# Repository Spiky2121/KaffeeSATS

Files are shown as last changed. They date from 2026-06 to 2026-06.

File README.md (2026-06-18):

# ☕⚡ KaffeeSATS

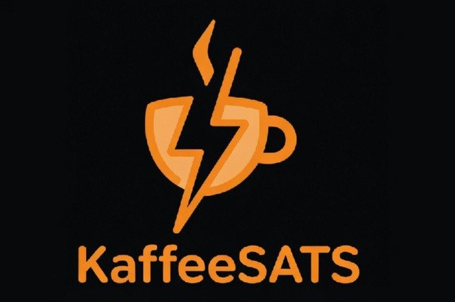
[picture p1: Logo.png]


## Pay With Lightning. Drink Coffee.

### Open-Source Bitcoin Coffee Machines

---

# 🌐 Project Website

## https://spiky2121.github.io/KaffeeSATS/

---

# 💻 GitHub Repository

## https://github.com/Spiky2121/KaffeeSATS

---

### ⚡ Features

* Lightning Payments
* Bolt Card NFC Support
* LNbits Offline Bitcoin Switch
* ZapBox Online Edition
* Bosch Tassimo Integration
* 3D Printed Parts
* Open Source Hardware
* Open Source Documentation

---

### ☕ Two Bitcoin Coffee Machines

#### 🔐 Offline Bitcoin Switch Edition

* Sunton ESP32-3248S035
* LNbits Offline Bitcoin Switch
* PIN-based Coffee Unlock
* Fully Offline Payment Verification

#### 💳 ZapBox Online Edition

* ZapBox Compact
* Lightning QR Payments
* Bolt Card NFC Payments
* Instant Coffee Unlock

---

### 📚 Documentation

* Wiring Guides
* Block Diagrams
* Build Instructions
* Hardware Modifications
* Safety Notes

---

### 🧩 Downloads

* A3 Conference Posters
* Wiring Diagrams
* 3D Print Files
* STEP Files
* Sticker Artwork

---

### 🚀 Project Goal

KaffeeSATS demonstrates how Bitcoin Lightning payments can interact with real-world hardware.

Scan. Pay. Press. Enjoy Coffee.

Built by a Bitcoiner, for Bitcoiners.

# Version 1: ☕ KaffeeSATS Offline Edition Bitcoin Switch

### Offline Lightning PIN System

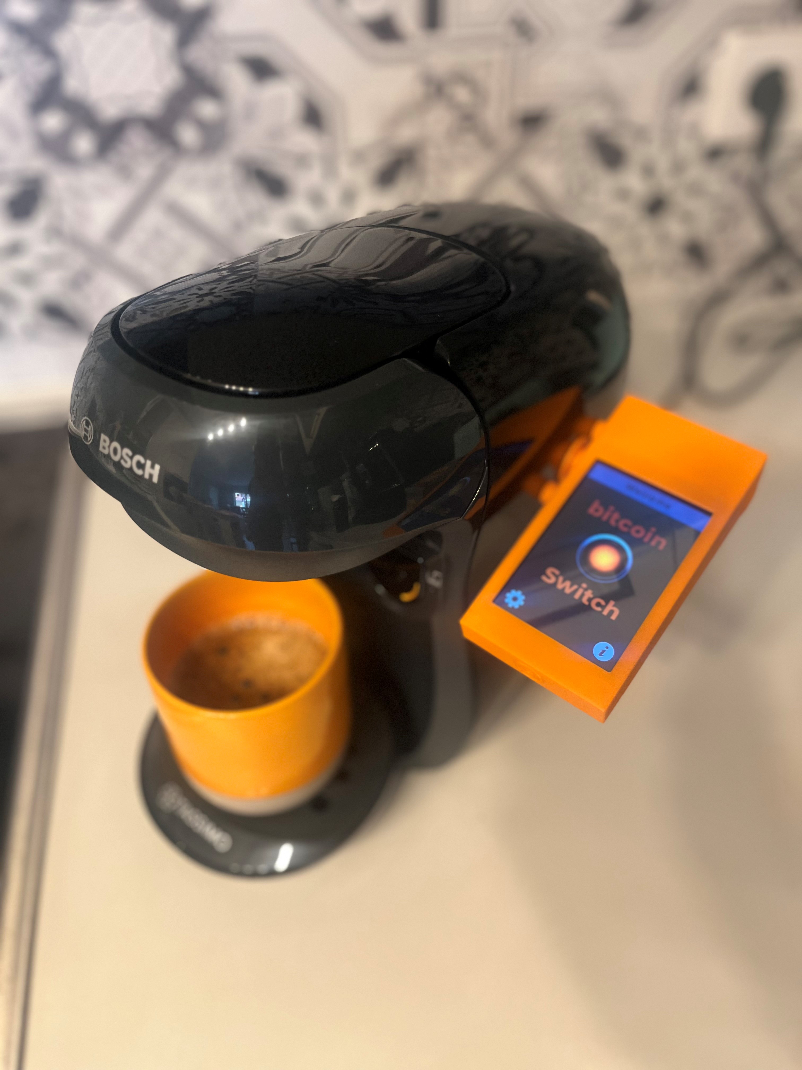
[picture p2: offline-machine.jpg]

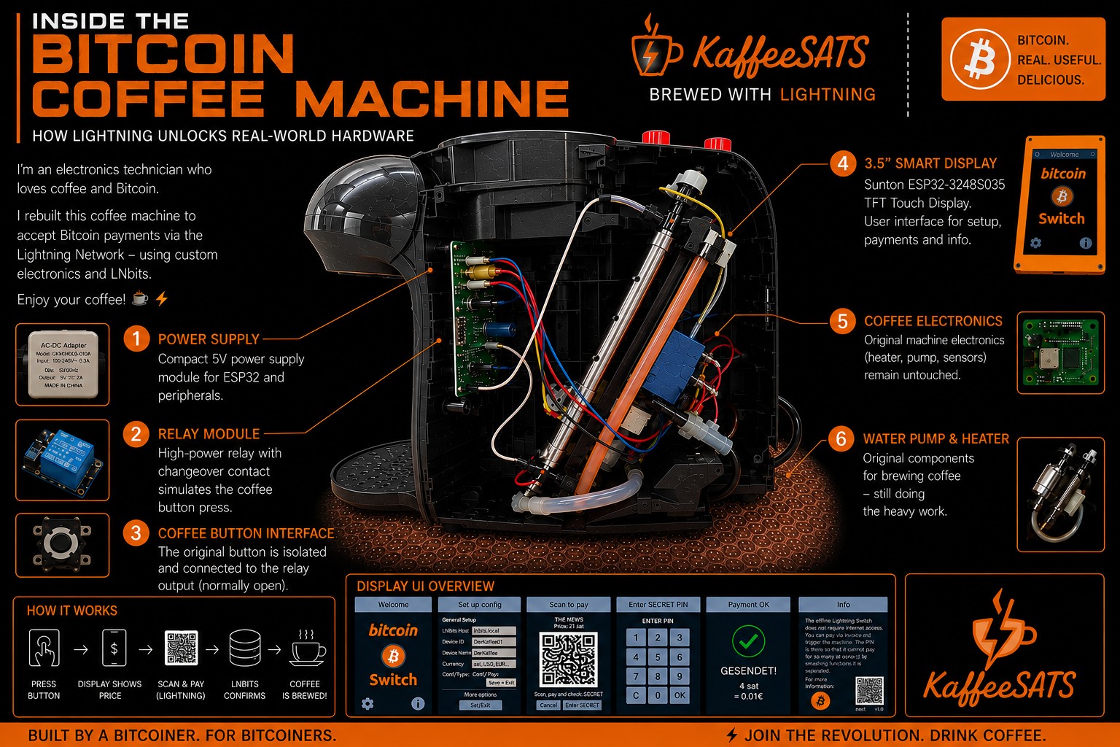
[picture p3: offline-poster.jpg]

Hardware:

* Sunton ESP32-3248S035 Smart Display
* LNbits Offline Bitcoin Switch
* Internal Relay Interface
* Bosch Tassimo Coffee Machine

How it works:

1. Scan Lightning invoice
2. Pay with any Lightning wallet
3. Receive a secret PIN
4. Enter PIN on the display
5. Relay activates
6. Press coffee button
7. Coffee brewing starts

Advantages:

* Works without permanent internet connection
* No external controller required
* Great demonstration of the LNbits Offline Bitcoin Switch

# ☕ KaffeeSATS Offline Edition – Wiring Guide

## Components

* 230V → 5V AC/DC Power Supply
* Sunton ESP32-3248S035 Display
* 5V Relay Module
* Bosch Tassimo Main Control Board
* Original Tassimo Start Button

---

## Power Supply

### AC Side

230V AC Supply:

* L (Live) → Power Supply Input L
* N (Neutral) → Power Supply Input N

### DC Side

Power Supply Output:

* +5V → Sunton ESP32 USB Power Input
* GND → Sunton ESP32 USB Power Input

---

## ESP32 → Relay Connection

The 3-pin connector on the side of the Sunton display is used:

| ESP32 | Relay |
| --- | ----- |
| Red (+5V) | VCC |
| Black (GND) | GND |
| Yellow (Signal) | IN |

The ESP32 controls the relay through the signal wire.

---

## Relay Contact

Only the isolated dry-contact output of the relay is used.

### Contact 1

Relay COM →

Button Pin 2

(Pin 2 of the original button is bent upward and electrically isolated.)

### Contact 2

Relay NO →

Neutral (N) connection on the Tassimo control board

---

## Button Modification

Original Button Layout:

| Pin | Function |
| --- | --- |
| 1 | Original Contact |
| 2 | Connected to Relay |
| 3 | Cut Off / Not Used |
| 4 | Original Contact |

Required Modifications:

* Bend Pin 2 upward
* Cut off Pin 3
* Connect relay contact to Pin 2

---

## Operating Principle

1. User scans Lightning invoice
2. Payment is confirmed
3. ESP32 activates relay
4. Relay connects:

   * Button Pin 2
   * Neutral point on the control board
5. Coffee machine becomes enabled
6. User presses the yellow Tassimo button
7. Coffee brewing starts

---

## Safety Notice

* 230V AC wiring should only be performed by qualified personnel.
* The relay contact is galvanically isolated from the ESP32.
* All mains voltage connections must be properly insulated.
* Ensure protection against accidental contact with live parts.

---
## Project Purpose

  KaffeeSATS Offline Edition
          LNbits Offline Bitcoin Switch

               230V AC
          ┌─────────────┐
          │   L     N   │
          └──┬─────┬────┘
             │     │
             ▼     ▼

      ┌─────────────────┐
      │ 230V → 5V PSU   │
      │ AC/DC Module    │
      └─────────────────┘
             │
        +5V  │  GND
             ▼

          Sunton ESP32-3248S035
        ┌───────────────────────┐
        │                       │
        │ Red (+5V)  ───────► VCC
        │                       │
        │ Black (GND) ──────► GND
        │                       │
        │ Yellow (GPIO21) ──► IN
        │                       │
        └───────────────────────┘
                        ▼
                        ▼
                    ┌────────────────┐
                    │ 5V Relay Module│
                    │                │
                    │ VCC ← +5V      │
                    │ GND ← GND      │
                    │ IN  ← GPIO21   │
                    └─────┬──────┬───┘
                          │      │
                         COM    NO
                          │      │
                          │      │
                          ▼      ▼

                   Pin 2      Neutral (N)
               (lifted pin)   Tassimo PCB

                          │
                          ▼

                 Original Tassimo
                    Start Button

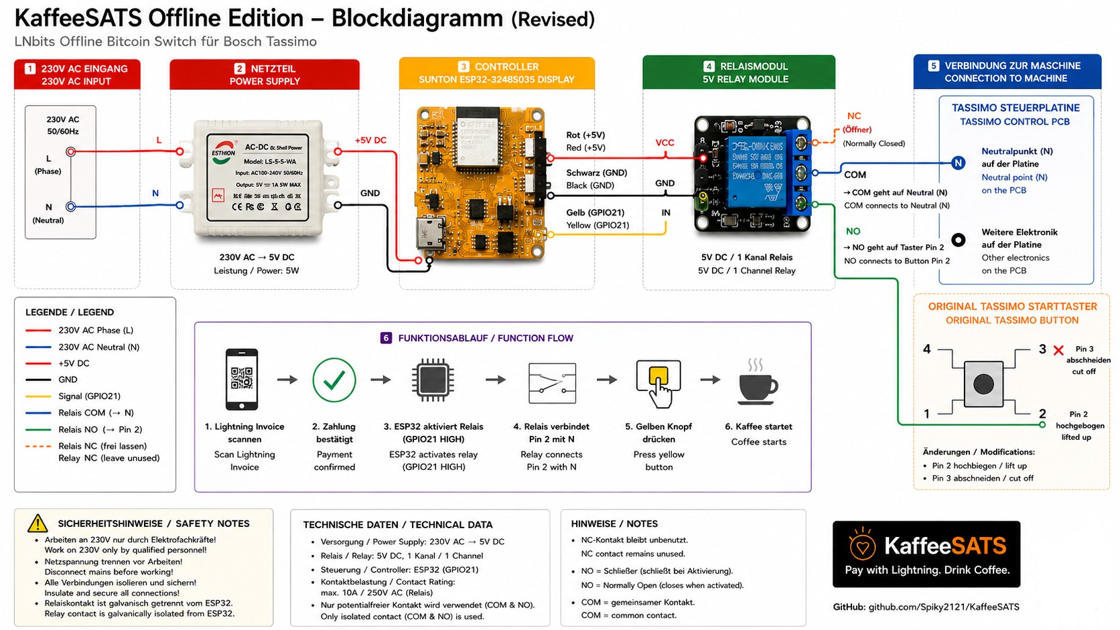
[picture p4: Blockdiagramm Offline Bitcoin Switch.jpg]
    

  # ⚡ Bitcoin Offline Switch Documentation

## https://ereignishorizont.xyz/offlinelnswitch/

# ⚡ Bitcoin Offline Switch Web Installer

## https://ereignishorizont.xyz/installer/offlineLNSwitch/index.html
---
---
---

# Version 2: ☕ KaffeeSATS Online ZapBox Edition

### Lightning & Bolt Card Enabled

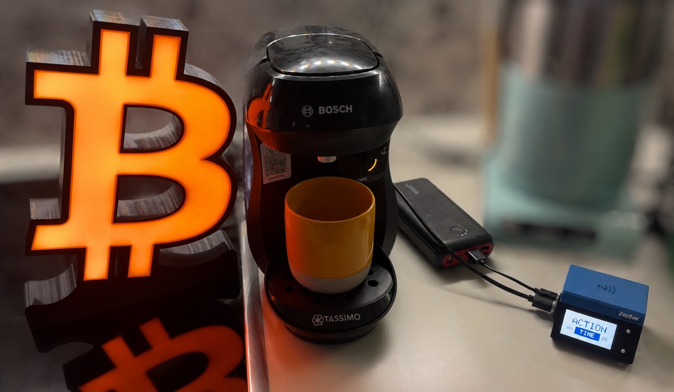
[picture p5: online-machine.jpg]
Online Version

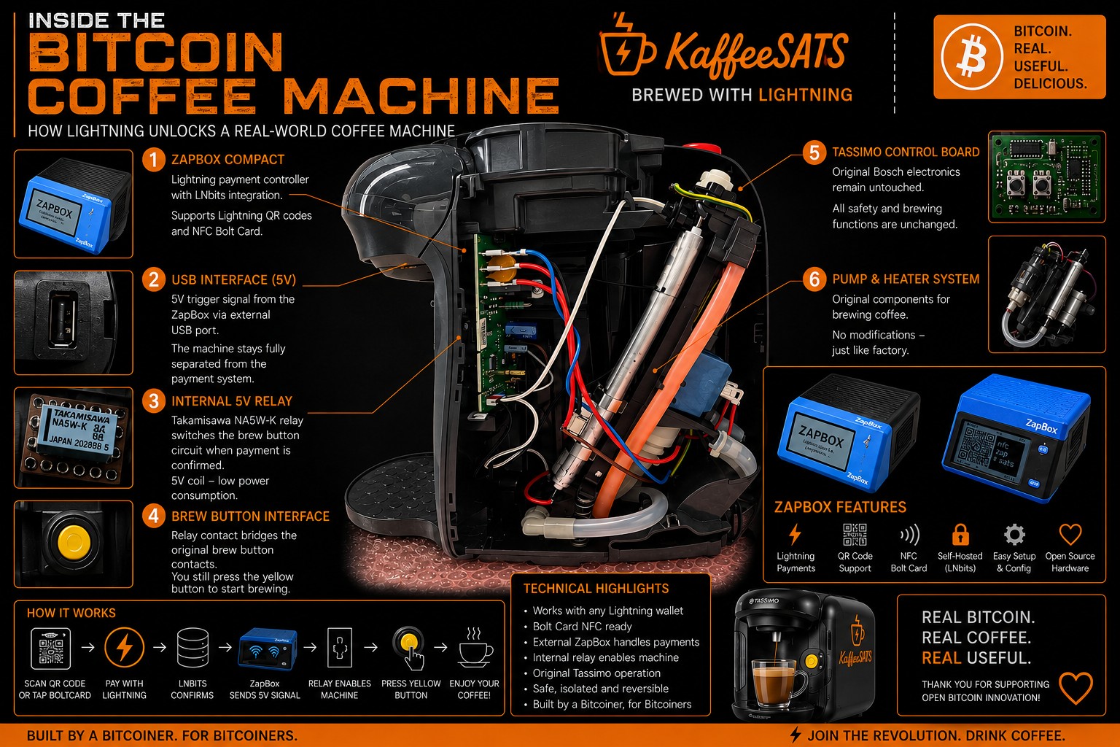
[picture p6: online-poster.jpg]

Hardware:

* ZapBox Compact
* LNbits
* Internal 5V Relay
* Bosch Tassimo Coffee Machine

How it works:

1. Scan QR Code
   or
   Tap NFC Bolt Card
2. Lightning payment is processed
3. ZapBox outputs a 5V trigger signal
4. Internal relay enables the machine
5. User presses the brew button
6. Coffee brewing starts

Advantages:

* Instant user experience
* NFC Bolt Card support
* Simple payment flow
* Perfect for conferences and public demonstrations

---

# ☕ KaffeeSATS Online Zapbox Edition - Wiring Guide

### ZapBox Lightning Payment Terminal for Bosch Tassimo

**Pay with Lightning. Drink Coffee.**

---

## Project Purpose

The KaffeeSATS Online Edition demonstrates how a Bitcoin Lightning payment can directly trigger a Bosch Tassimo coffee machine.

The ZapBox handles:

* Lightning payments
* QR code generation
* Bolt Card NFC payments
* Payment verification

After a successful payment, the ZapBox outputs **5V** via USB and activates an internal relay. The relay enables the original Tassimo start button.

---

## Hardware Components

* ZapBox Payment Terminal
* USB Power Output (5V)
* Takamisawa NA5W-K Relay
* Bosch Tassimo Control PCB
* Original Tassimo Start Button

---

## System Overview

```text
                ┌──────────────────┐
                │      ZapBox      │
                │ Lightning Wallet │
                └─────────┬────────┘
                          │
                          │ USB 5V Output
                          ▼

                ┌──────────────────┐
                │ Internal Relay   │
                │ Takamisawa NA5W-K│
                └──────┬─────┬─────┘
                       │     │
                      COM    NO
                       │     │
                       │     ▼
                       │  Neutral (N)
                       │  Tassimo PCB
                       │
                       ▼

                  Pin 2 Button
                 (lifted from PCB)

                       │
                       ▼

              Original Tassimo
                 Start Button
```

---

## USB Power Output

The ZapBox provides 5V through the internal USB connector.

| Wire  | Function |
| ----- | --- |
| Red | +5V |
| Black | GND |

Connections:

```text
ZapBox USB
----------------
Red   -> Relay Coil +
Black -> Relay Coil -
```

---

## Relay Contact Wiring

Only the isolated relay contact is used.

| Relay Contact | Connection |
| --- | --- |
| COM | Button Pin 2 |
| NO | Neutral (N) on Tassimo PCB |
| NC | Not Connected |

---

## Button Modification

Original tactile switch:

```text
4 ----- 3
|       |
|   ●   |
|       |
1 ----- 2
```

Required modification:

* Lift Pin 2 from PCB
* Connect relay COM to Pin 2
* Cut Pin 3
* Leave Pins 1 and 4 unchanged

---

## Function Flow

1. User scans Lightning invoice
2. Payment is confirmed
3. ZapBox outputs 5V
4. Internal relay activates
5. Relay connects:

   * COM → Pin 2
   * NO → Neutral (N)
6. User presses the Tassimo button
7. Coffee starts

---
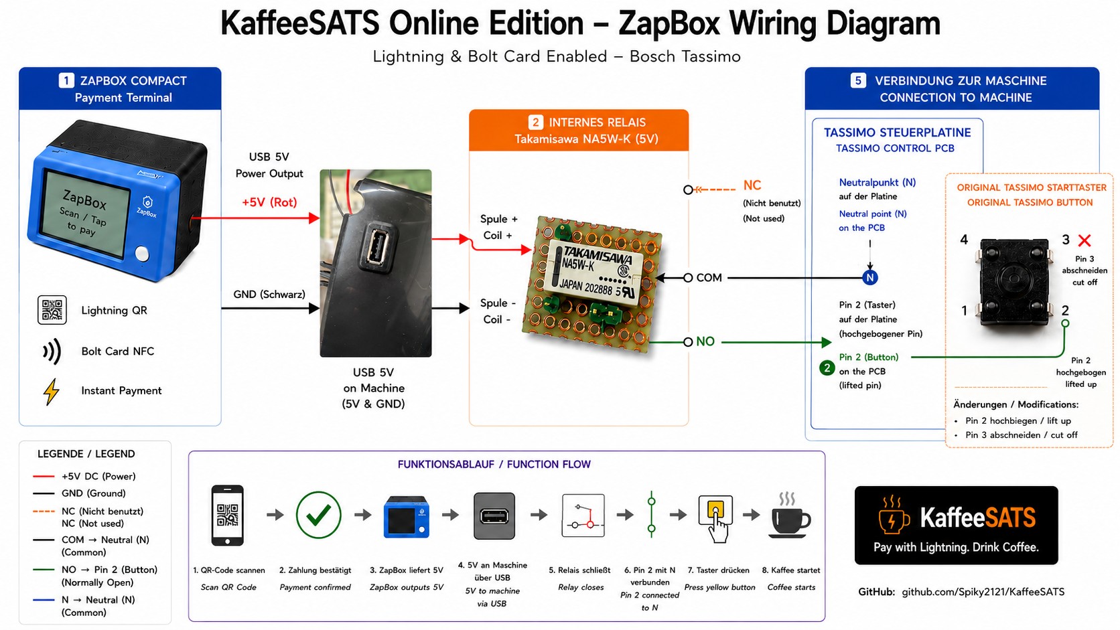
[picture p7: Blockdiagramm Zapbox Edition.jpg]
   
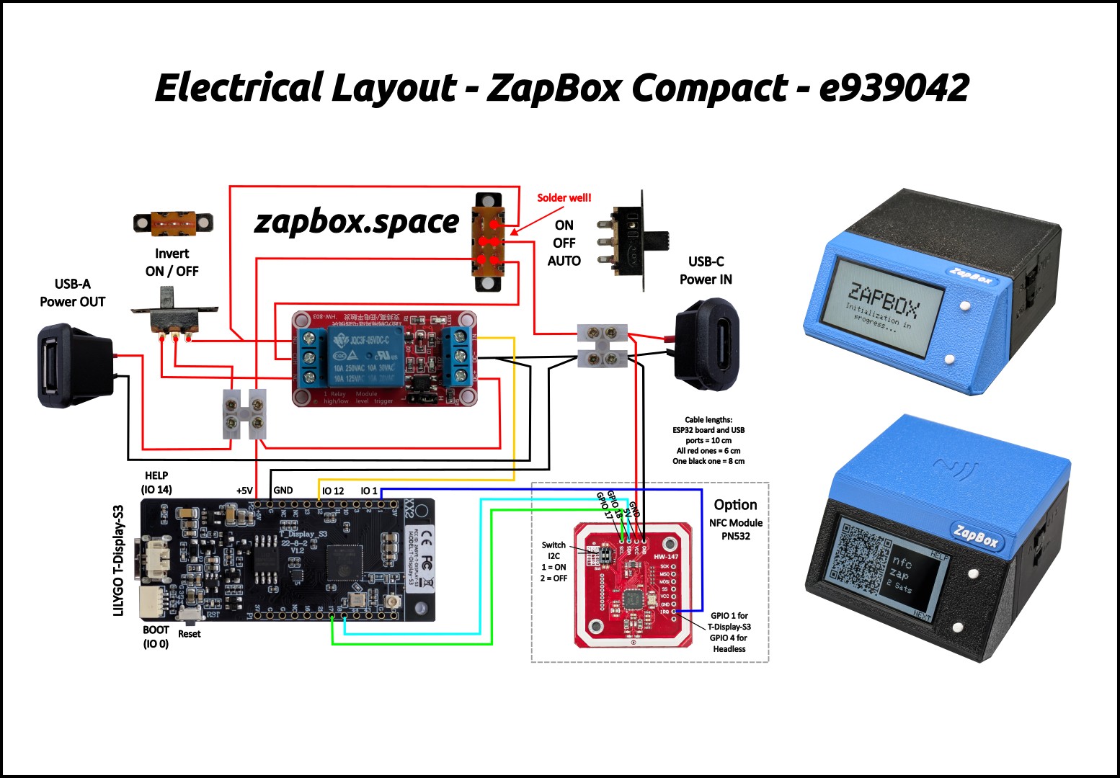
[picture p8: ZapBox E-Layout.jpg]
 

# ⚡ Zapbox Documentation
 
##  https://github.com/AxelHamburch/ZapBox
##  https://zapbox.space/

# ⚡ ZapBox Web Installer

## 👉 [Flash ZapBox Firmware](https://installer.zapbox.space/#flash)
 
## Safety Notice

⚠️ This modification involves mains-powered equipment.

* Disconnect power before working on the machine.
* Insulate all wiring properly.
* Verify relay isolation before operation.
* Only qualified persons should work on electrical equipment.

---

### KaffeeSATS

**Pay with Lightning. Drink Coffee.**

# Comparison

| Feature | Offline Switch | ZapBox |
| --- | --- | --- |
| Lightning QR | ✅ | ✅ |
| NFC Bolt Card | ❌ | ✅ |
| Secret PIN | ✅ | ❌ |
| Sunton Display | ✅ | Optional |
| ZapBox | ❌ | ✅ |
| Offline Operation | ✅ | ❌ |
| Conference Friendly | ✅ | ✅ |

---

# Why KaffeeSATS?

Bitcoin is often difficult to explain.

Coffee is not.

KaffeeSATS demonstrates Bitcoin and the Lightning Network through a real-world interaction that everyone understands.

Pay.
Press.
Enjoy.

---

## Sticker 
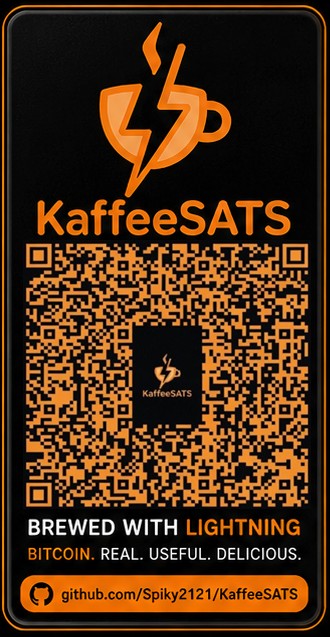
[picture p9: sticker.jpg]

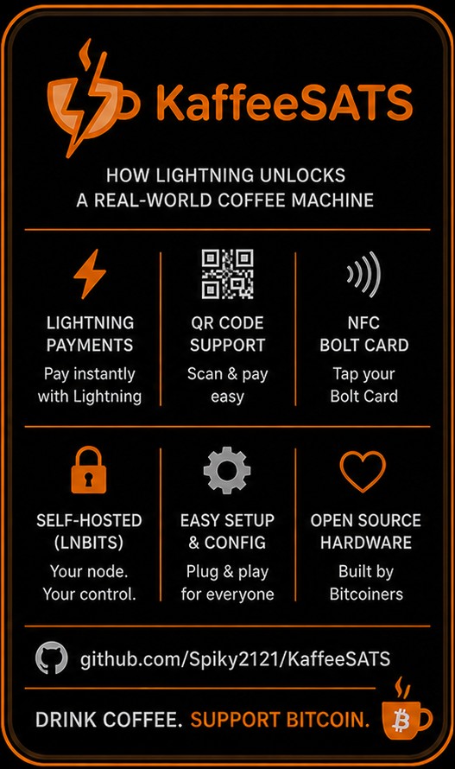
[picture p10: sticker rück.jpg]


## Business Card 
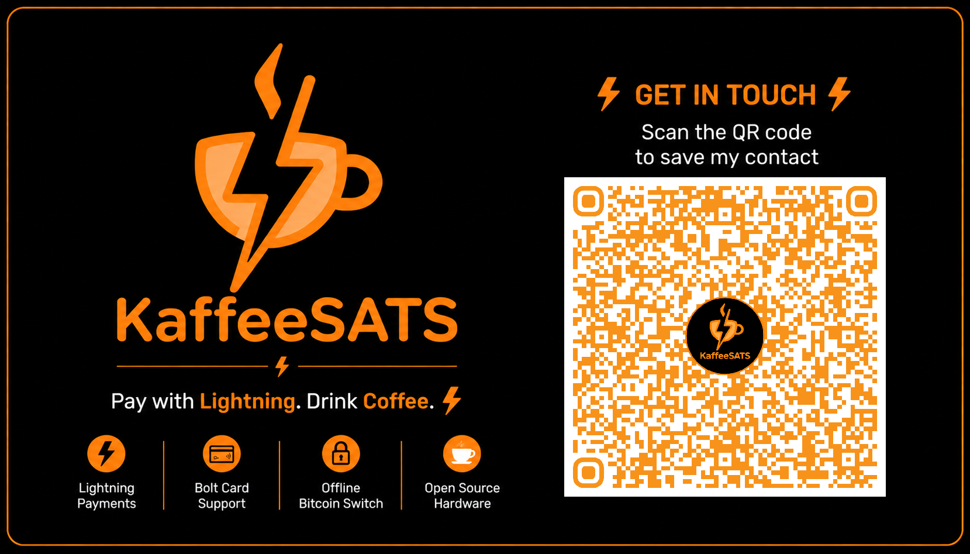
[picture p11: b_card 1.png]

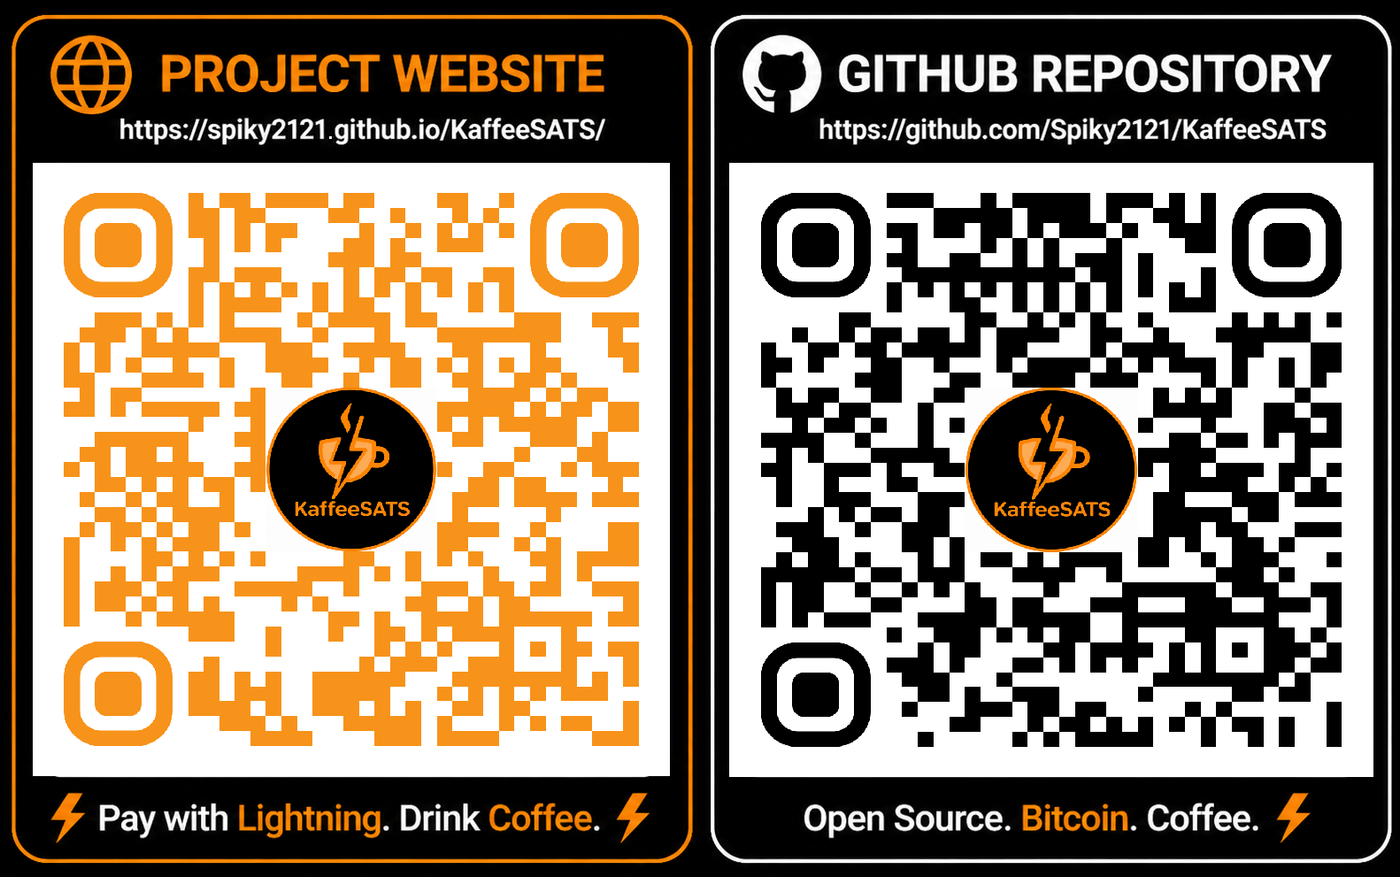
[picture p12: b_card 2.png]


# Open Source

This project is released under the MIT License.

Feel free to fork, improve and build your own Bitcoin-powered coffee machine.

## Acknowledgements

Special thanks to Axel (www.ereignishorizont.xyz) & (www.zapbox.space) for the development of ZapBox and the Offline Bitcoin Switch.
---
---
Thanks to the LNbits team and timecatcher.lnbits for providing the open-source payment infrastructure (https://lnbits.com/) & (https://timecatcher.business-bitcoin.de/)
---
---
# KaffeeSATS

### Pay With Lightning. Drink Coffee.

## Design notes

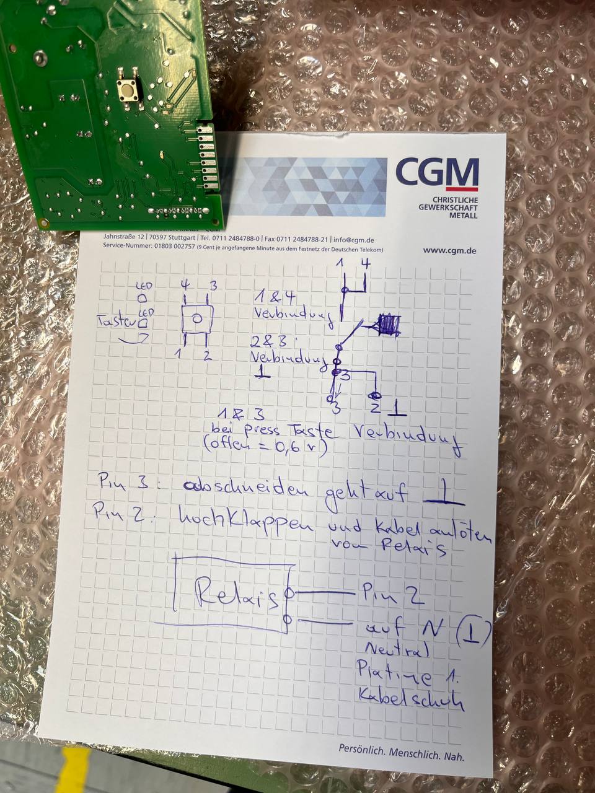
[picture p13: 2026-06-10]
Images/Hack the button ,schematic.jpg

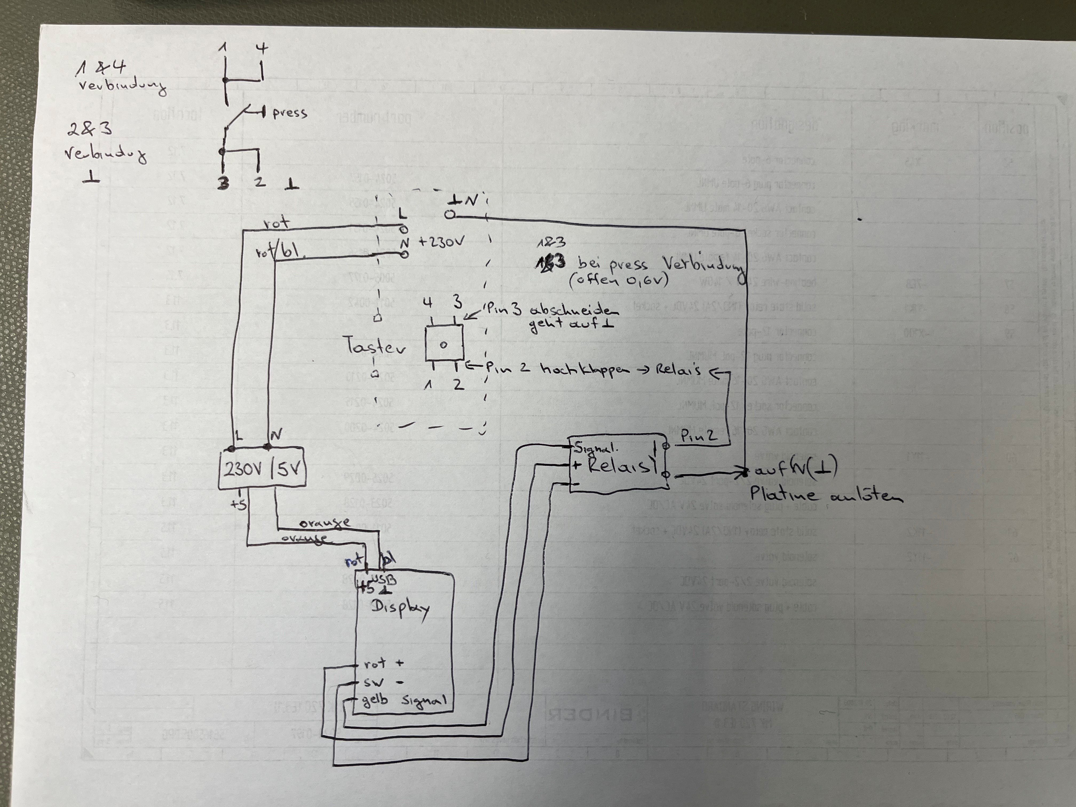
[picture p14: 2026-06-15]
Images/main schematic.jpg

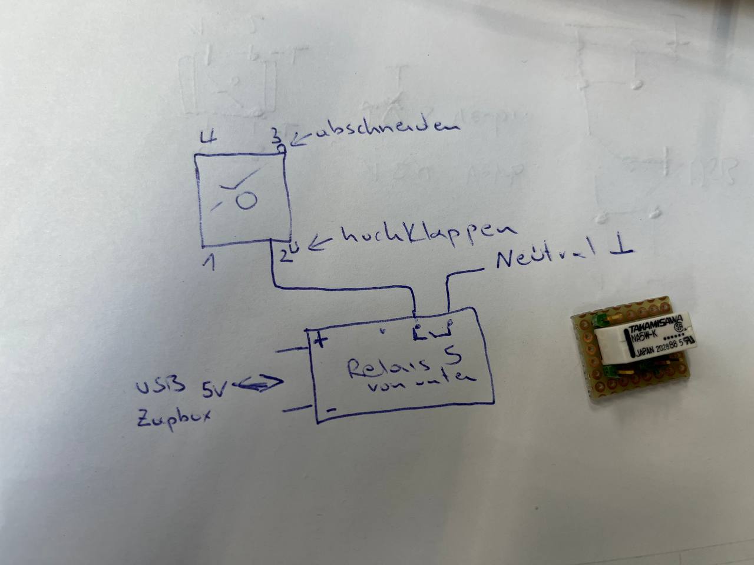
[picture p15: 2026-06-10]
Images/schematic relays.jpg

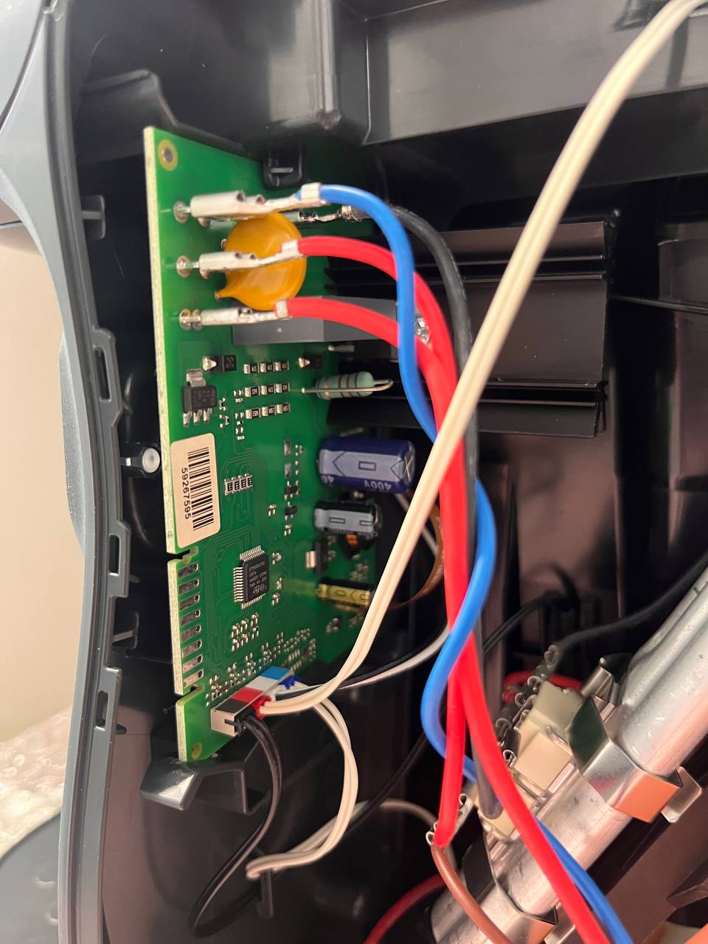
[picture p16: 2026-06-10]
Images/Tassimo Electronic Board.jpg

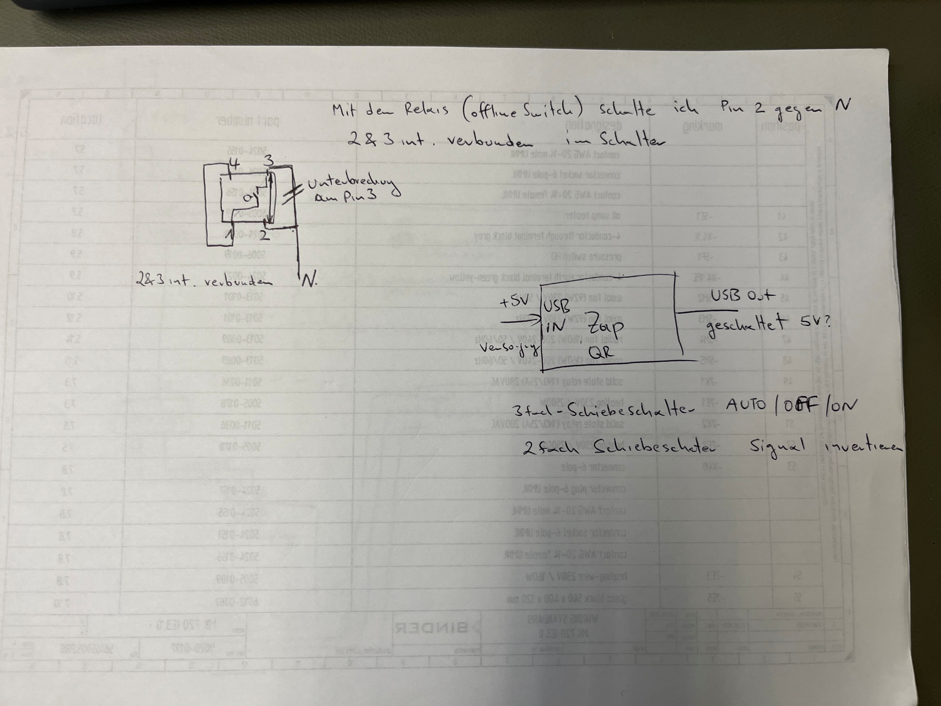
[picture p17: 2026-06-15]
Images/switch schematic.jpg

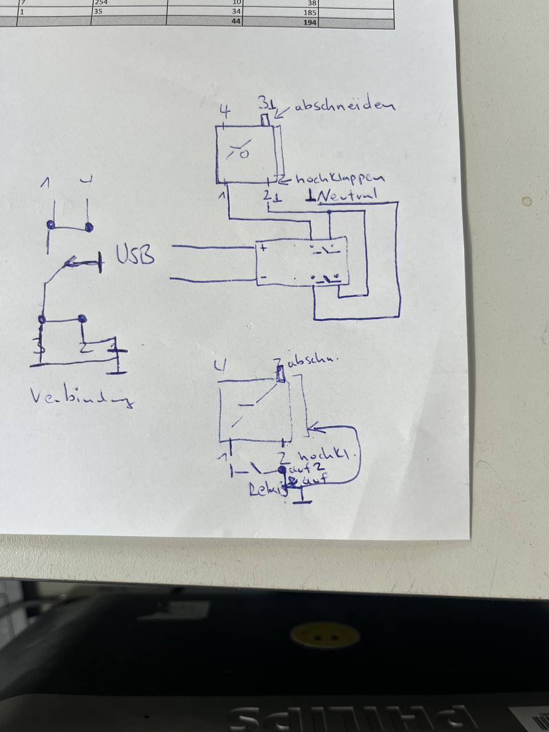
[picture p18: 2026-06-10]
Images/schematic 2.jpg

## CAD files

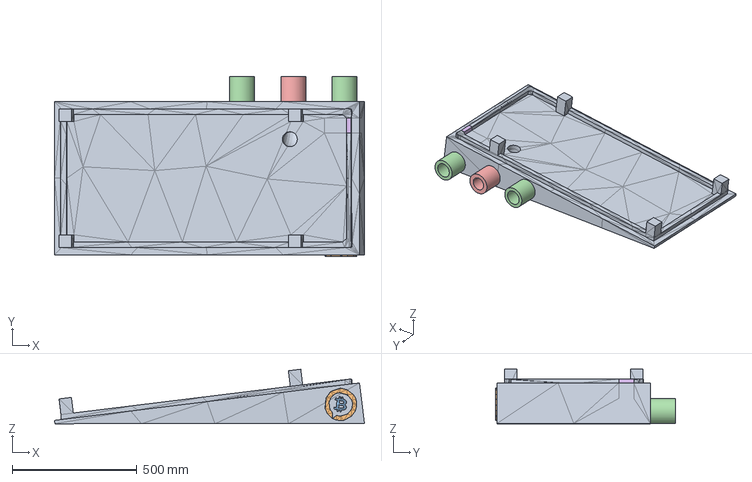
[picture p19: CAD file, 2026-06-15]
3D Print/Unterteil Final.step
1240.8 x 719.0 x 218.3 mm

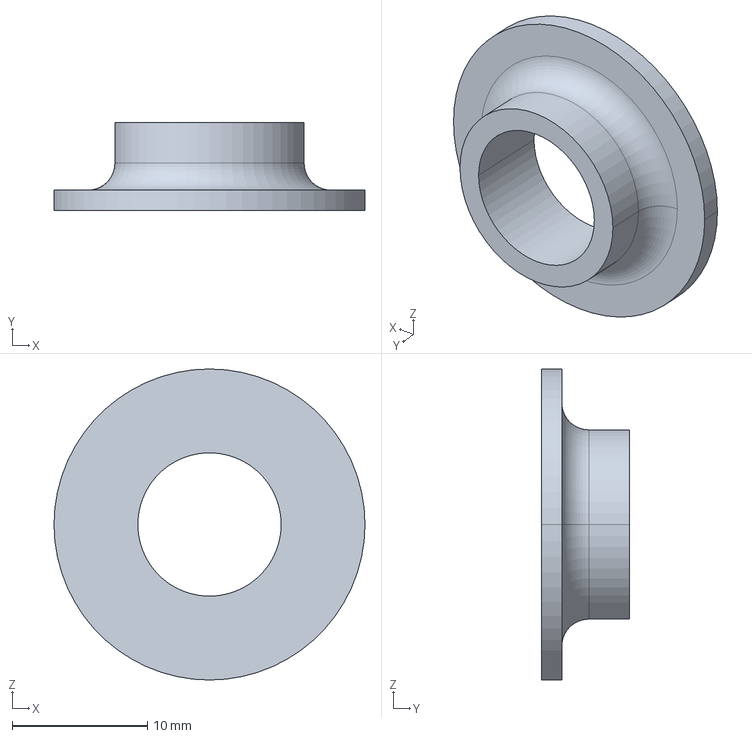
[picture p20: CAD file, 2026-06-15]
3D Print/Cable Entry.stp
23.0 x 6.50 x 23.0 mm

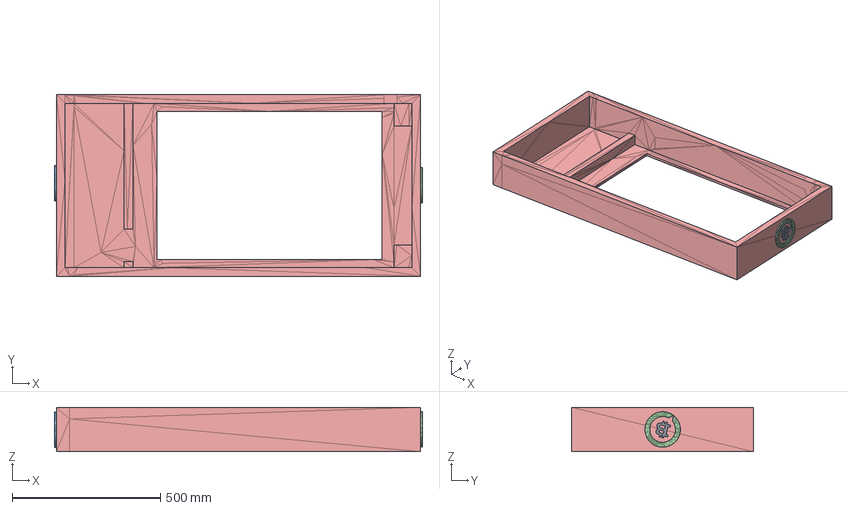
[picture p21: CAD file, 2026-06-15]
3D Print/Oberteil Final.step
1242.0 x 613.0 x 150.0 mm

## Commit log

2026-06-16 Create 3D Print
2026-11-04 Rename Cable Entry.stl to Cable_Entry.stl
2026-11-04 Rename Oberteil Final.stl to Oberteil_Final.stl
2026-11-04 Rename Unterteil Final.stl to Unterteil_Final.stl
